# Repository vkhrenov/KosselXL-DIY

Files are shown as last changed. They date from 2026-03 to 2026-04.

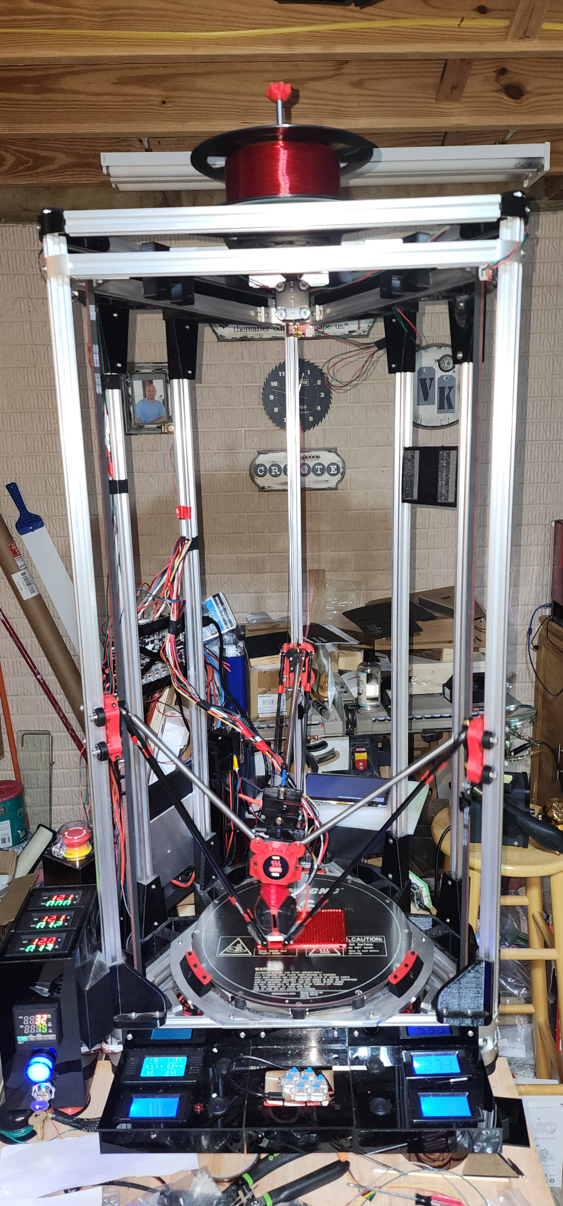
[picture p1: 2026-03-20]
Work in progress.jpg

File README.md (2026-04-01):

# KosselXL-DIY

DIY Delta 3D printer build based on a Kossel XL frame, upgraded with a BigTreeTech Manta M8P controller and Klipper firmware.

This repository documents the machine configuration, parts, and setup process.

## Project Goals

- Rebuild and modernize a classic Kossel XL style Delta printer.
- Use a modern 32-bit control board (BigTreeTech Manta M8P).
- Run Klipper for better kinematics handling and easier tuning.
- Keep the project open and easy to reproduce.

## Hardware Overview

- Frame type: Delta (Kossel XL style)
- Mainboard: BigTreeTech Manta M8P
- Firmware stack: Klipper + Moonraker + Mainsail
- Configuration files: located in `Klipper/`

Current Klipper configs in this repository:

- `Klipper/printer.cfg`
- `Klipper/mainsail.cfg`
- `Klipper/moonraker.conf`
- `Klipper/user_macros.cfg`
- `Klipper/sonar.conf`
- `Klipper/timelapse.cfg`

## Repository Structure

- `Klipper/`: machine and service configuration for Klipper stack
- `Blender/`: 3D model related files and notes
- `Parts/`: printable or mechanical part references

## Recommended Build and Setup Flow

1. Assemble frame, towers, linear motion system, and effector.
2. Install the Manta M8P and wire all components:
   - stepper motors
   - endstops
   - hotend heater and thermistor
   - bed heater and thermistor (if heated bed is used)
   - part cooling and hotend fans
   - probe/sensor (if installed)
3. Install Klipper host software (typically on a Raspberry Pi or similar Linux SBC).
4. Flash Klipper firmware to the Manta M8P.
5. Copy and adapt config files from `Klipper/` to your active Klipper config folder.
6. Verify motion direction and endstop logic before any homing test.
7. Run Delta calibration and then print tuning.

## Safety Checklist (Before First Heat or Motion)

- Confirm correct PSU voltage and grounding.
- Check all heater and thermistor ports carefully.
- Validate max temperature limits in config.
- Test endstops with `QUERY_ENDSTOPS` before homing.
- Keep one hand near power-off during first movement tests.
- Never leave first thermal tests unattended.

## Delta Calibration Checklist

After basic axis movement is verified:

1. Home the printer safely.
2. Set rough geometry values (arm length, radius, endstop positions).
3. Run Klipper Delta calibration routine.
4. Re-check first layer consistency across the full bed area.
5. Tune extrusion and temperature for your filament.

## Software and Service Notes

This project uses:

- Klipper for motion control
- Moonraker for API/service layer
- Mainsail as web UI

Service-specific configuration lives in the `Klipper/` folder and can be adapted to your environment.

## Status

Work in progress.

Planned additions:

- Wiring diagram for Manta M8P pin mapping
- BOM with exact part numbers
- Step-by-step commissioning logs
- Known-good slicer profiles

## License

See `LICENSE` for license details.

## Credits

40mm Fan Guard by Prot0typ1cal https://www.thingiverse.com/thing:1662879

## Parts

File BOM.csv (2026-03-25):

Item ID | Category | Part | Specification | Qty | Unit | Supplier | Part Number | Unit Cost | Total Cost | Status | Notes
1 | Frame | Aluminum extrusion | 2020 profile (cut to frame lengths) | 12 | pcs | TBD | TBD | 0 | 0 | To Buy | Confirm exact lengths and count
2 | Frame | Corner brackets | 2020-compatible L bracket | 24 | pcs | TBD | TBD | 0 | 0 | To Buy
3 | Motion | Linear rails or wheel system | Tower motion hardware set | 3 | sets | TBD | TBD | 0 | 0 | To Buy | Choose final tower motion design
4 | Motion | GT2 belt | 6 mm width | 5 | m | TBD | TBD | 0 | 0 | To Buy
5 | Motion | GT2 pulley | 20T 5 mm bore | 3 | pcs | TBD | TBD | 0 | 0 | To Buy
6 | Motion | GT2 idler | Smooth idler pulley | 6 | pcs | TBD | TBD | 0 | 0 | To Buy
7 | Motion | Stepper motor | NEMA 17 (X/Y/Z towers) | 3 | pcs | TBD | TBD | 0 | 0 | To Buy
8 | Motion | Extruder stepper | NEMA 17 (extruder) | 1 | pcs | TBD | TBD | 0 | 0 | To Buy
9 | Extrusion | Extruder | Titan or equivalent | 1 | pcs | TBD | TBD | 0 | 0 | To Buy
10 | Extrusion | Hotend | E3D V6 compatible | 1 | pcs | TBD | TBD | 0 | 0 | To Buy
11 | Thermal | Heater cartridge | 24 V 40 W | 1 | pcs | TBD | TBD | 0 | 0 | To Buy
12 | Thermal | Thermistor | NTC 100K | 1 | pcs | TBD | TBD | 0 | 0 | To Buy
13 | Cooling | Part cooling fan | 5015 blower 24 V | 1 | pcs | TBD | TBD | 0 | 0 | To Buy
14 | Cooling | Hotend fan | 4010 fan 24 V | 1 | pcs | TBD | TBD | 0 | 0 | To Buy
15 | Electronics | Mainboard | BigTreeTech Manta M8P | 1 | pcs | TBD | TBD | 0 | 0 | To Buy
16 | Electronics | Stepper drivers | TMC2209 or equivalent | 4 | pcs | TBD | TBD | 0 | 0 | To Buy | Update qty if adding more motors
17 | Electronics | SBC | Raspberry Pi or equivalent | 1 | pcs | TBD | TBD | 0 | 0 | To Buy
18 | Electronics | Power supply | 24 V PSU (sized for heaters + motors) | 1 | pcs | TBD | TBD | 0 | 0 | To Buy
19 | Electronics | Endstops | Mechanical or optical endstop switches | 3 | pcs | TBD | TBD | 0 | 0 | To Buy
20 | Bed | Build plate | Glass/PEI build surface | 1 | pcs | TBD | TBD | 0 | 0 | To Buy
21 | Bed | Heated bed | Round bed 24 V (optional) | 1 | pcs | TBD | TBD | 0 | 0 | Optional
22 | Wiring | Wire set | Silicone wire assorted gauges | 1 | set | TBD | TBD | 0 | 0 | To Buy
23 | Wiring | Connectors | Ferrules/JST/XH set | 1 | set | TBD | TBD | 0 | 0 | To Buy
24 | Fasteners | Screw assortment | M3/M4 screws nuts washers spacers | 1 | set | TBD | TBD | 0 | 0 | To Buy
25 | Printed Parts | Printable parts bundle | All STL files in Parts folder | 1 | bundle | Self print | N/A | 0 | 0 | In Progress | Track filament usage separately
26 | Tools | Crimping and assembly tools | Crimper hex keys cutters multimeter | 1 | set | Existing | N/A | 0 | 0 | Have | Only buy missing tools
27 | Spares | Consumables | Nozzles PTFE ties heatshrink | 1 | set | TBD | TBD | 0 | 0 | To Buy
28 | Documentation | Wiring labels | Heat-resistant cable labels | 1 | set | TBD | TBD | 0 | 0 | To Buy
 |  | TOTAL |  |  |  |  |  |  | 0

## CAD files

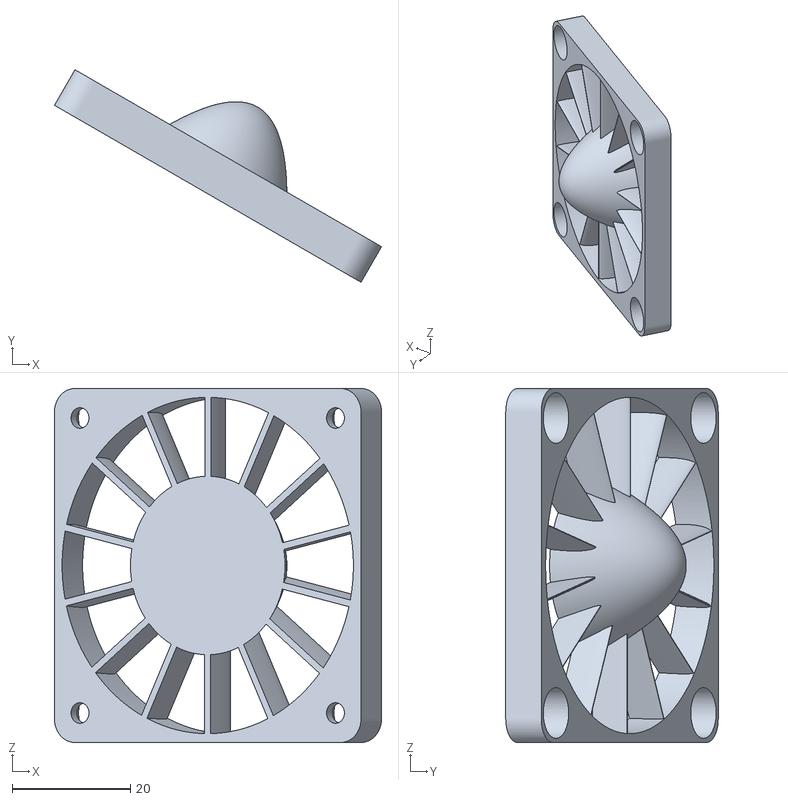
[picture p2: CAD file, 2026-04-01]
Parts/KosselXL-DIY-Fan_guard_60_back.stl
55.4 x 36.0 x 60.0

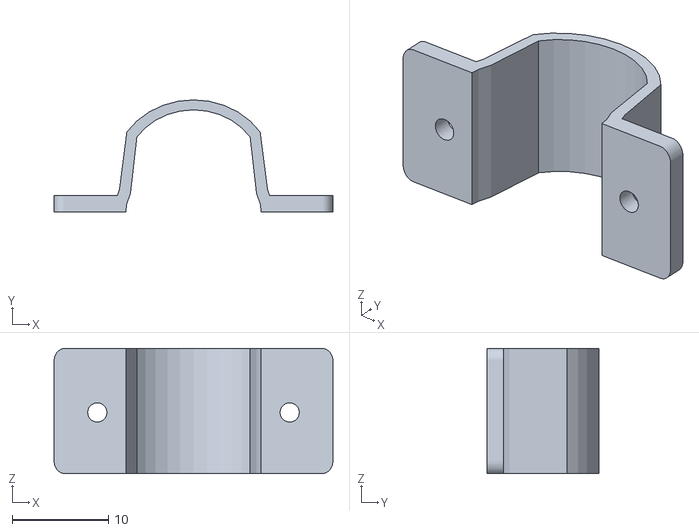
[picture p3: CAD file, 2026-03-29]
Parts/KosselXL-DIY-Wire_holder.stl
29.0 x 11.7 x 13.0

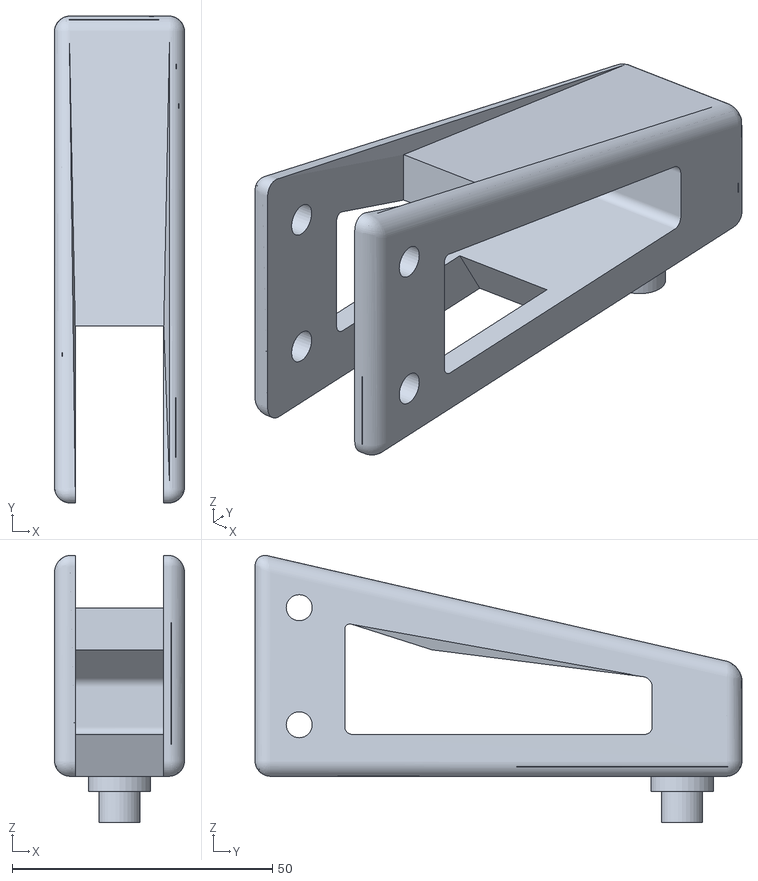
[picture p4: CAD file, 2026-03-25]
Parts/KosselXL-DIY-Guide.stl
25.0 x 93.6 x 51.3

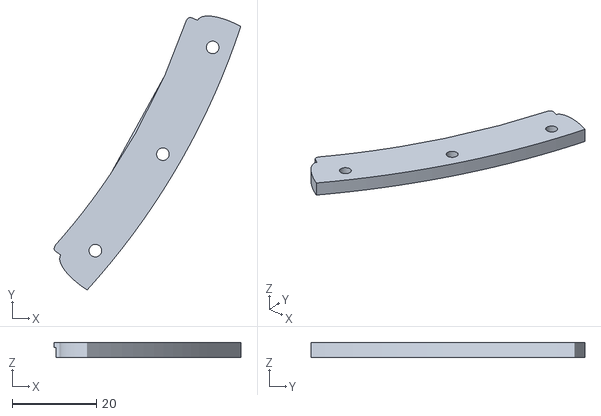
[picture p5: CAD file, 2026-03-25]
Parts/KosselXL-DIY-Build plate holder glass_Y.stl
44.3 x 65.1 x 3.50

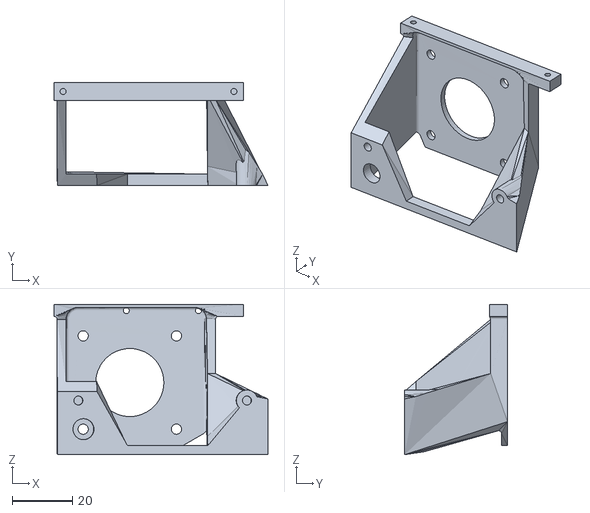
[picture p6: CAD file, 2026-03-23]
Parts/KosselXL-DIY-Titan_Mount.stl
71.1 x 34.2 x 50.0

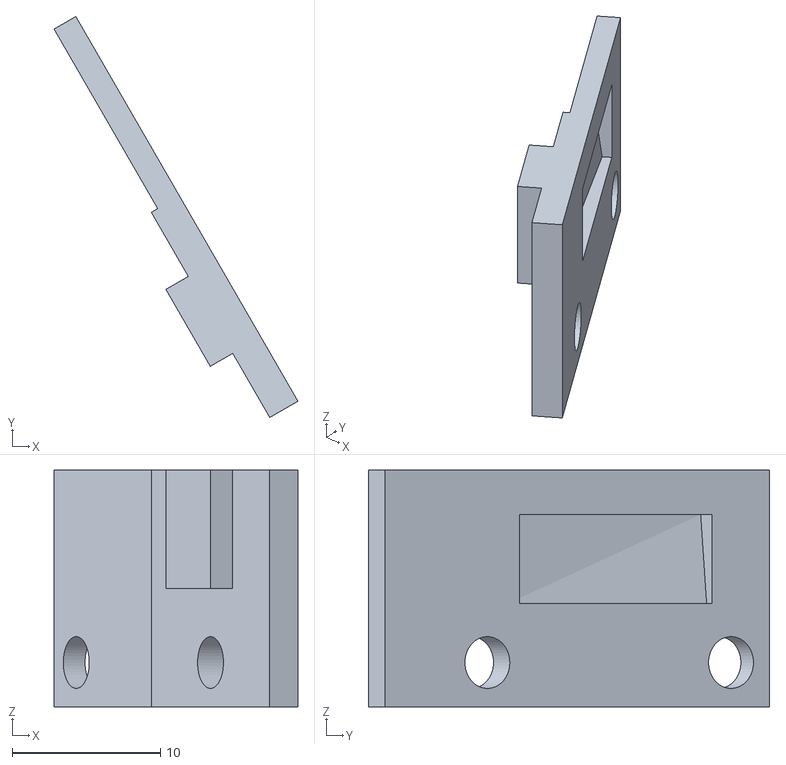
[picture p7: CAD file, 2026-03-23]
Parts/KosselXL-DIY-end_stop_mount_X.stl
16.5 x 27.1 x 16.0

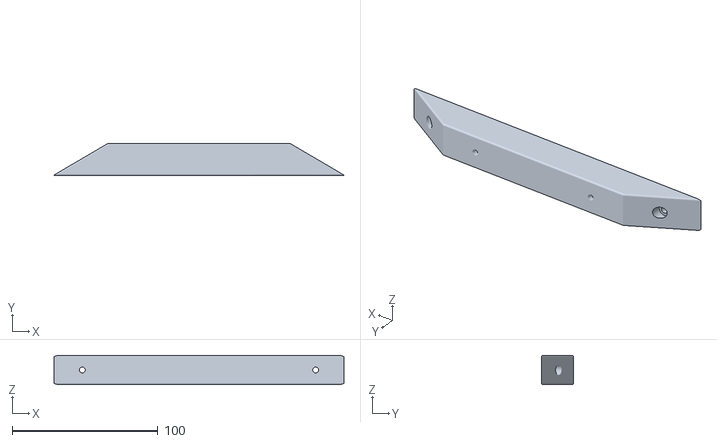
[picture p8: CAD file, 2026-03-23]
Parts/KosselXL-DIY-Spool mount holder.stl
198.9 x 22.0 x 20.0

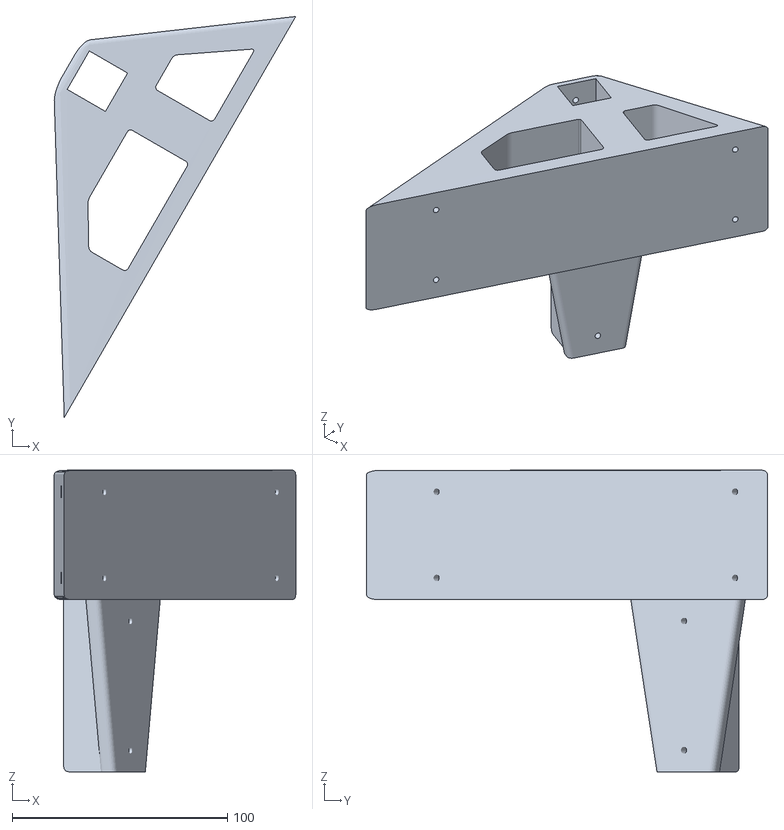
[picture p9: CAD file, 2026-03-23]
Parts/KosselXL-DIY-Reinforcement frame mount LT2.stl
112.1 x 186.2 x 140.0

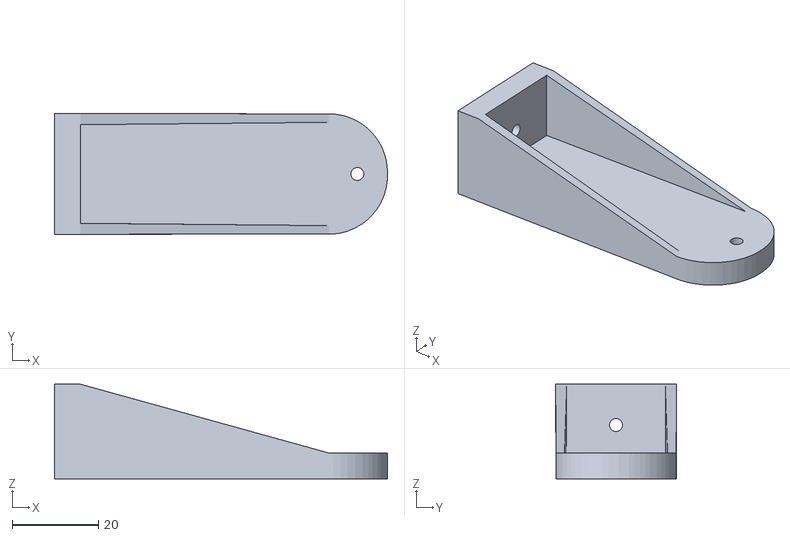
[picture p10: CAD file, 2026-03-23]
Parts/KosselXL-DIY-Upper Light right holder.stl
77.4 x 28.0 x 22.0

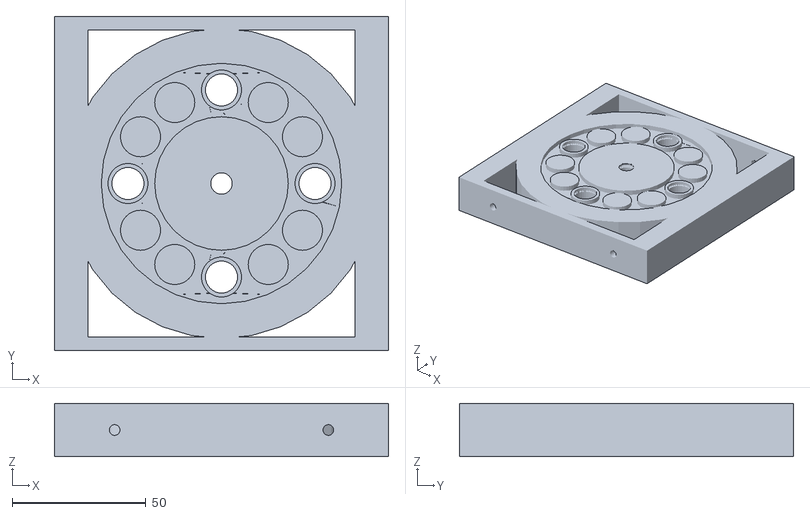
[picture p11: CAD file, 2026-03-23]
Parts/KosselXL-DIY-Spool Mount.stl
125.0 x 125.0 x 20.0

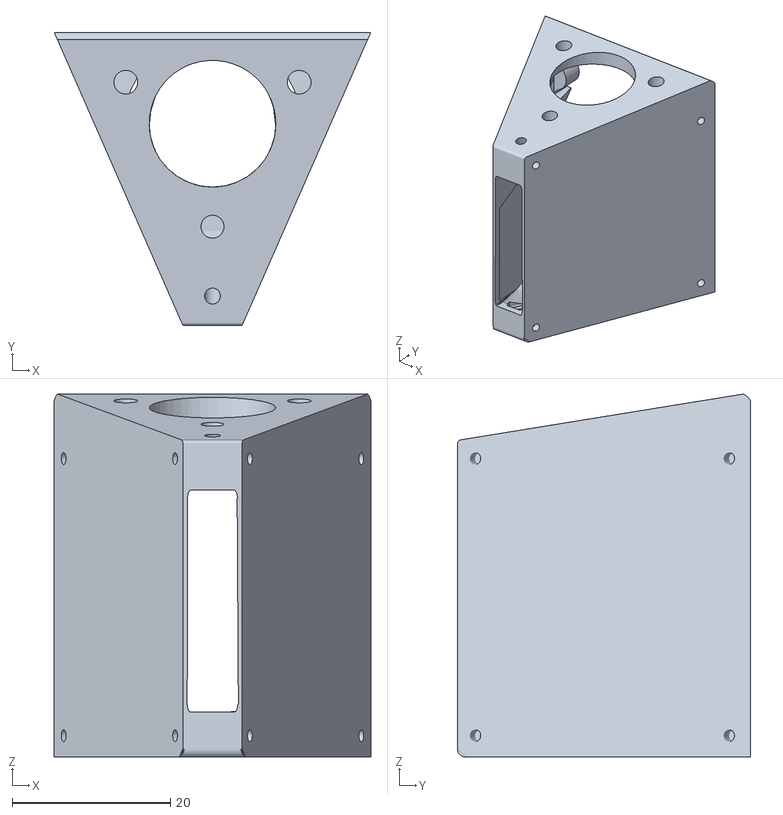
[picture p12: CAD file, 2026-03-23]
Parts/KosselXL-DIY-Frame.stl
40.0 x 37.1 x 45.9

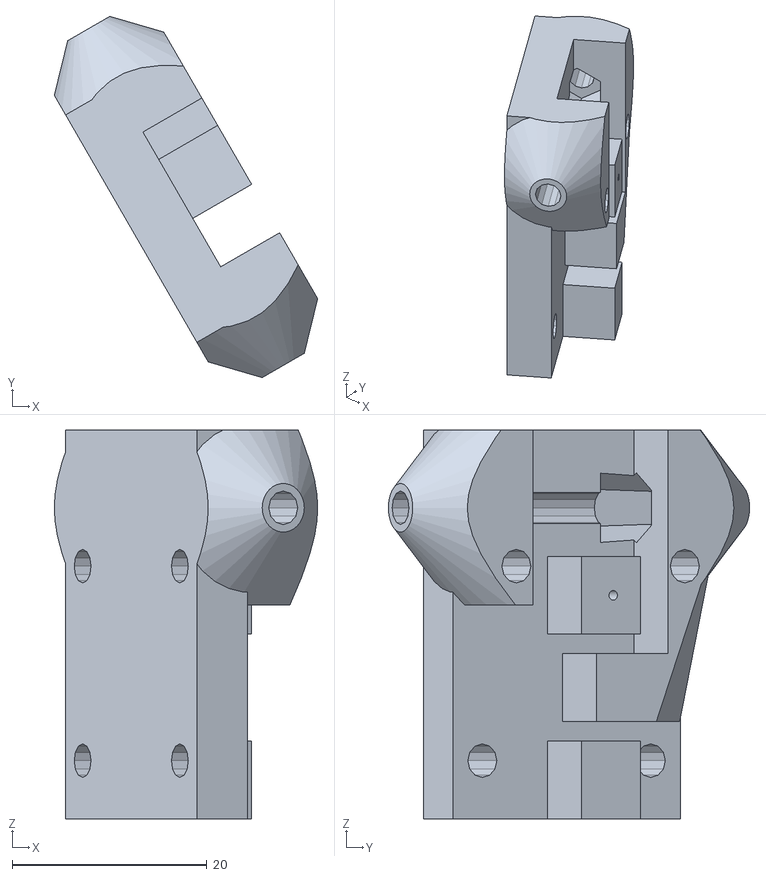
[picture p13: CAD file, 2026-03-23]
Parts/KosselXL-DIY-3X carriage_X.stl
27.1 x 37.1 x 40.0

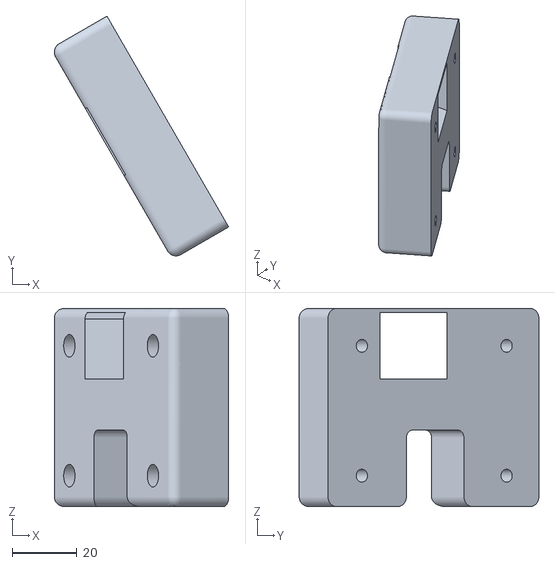
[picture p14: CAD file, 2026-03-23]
Parts/KosselXL-DIY-Right Center beam mount.stl
53.7 x 73.8 x 61.0

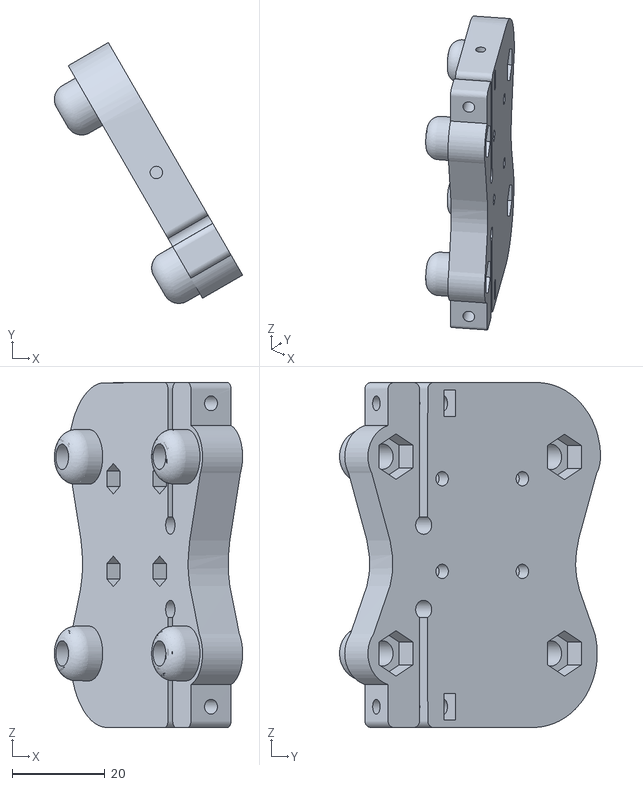
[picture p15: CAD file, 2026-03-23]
Parts/KosselXL-DIY-4Wheel_carraige_X.stl
40.6 x 56.3 x 74.5

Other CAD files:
Parts/KosselXL-DIY-Fan_guard_60_front.stl
Parts/KosselXL-DIY-Neck.stl
Parts/KosselXL-DIY-Spring_mount_front.stl
Parts/KosselXL-DIY-e3d_holder.stl
Parts/KosselXL-DIY-4Wheel_carraige_v1.stl
Parts/KosselXL-DIY-Build Plate Holder_Y.stl
Parts/KosselXL-DIY-EndStop callibrator.stl
Parts/KosselXL-DIY-Fan_shroud_right.stl
Parts/KosselXL-DIY-Guide base.stl
Parts/KosselXL-DIY-Guide wheel spacer.stl
Parts/KosselXL-DIY-Left Center beam mount.stl
Parts/KosselXL-DIY-Left beam mount.stl
Parts/KosselXL-DIY-Light_Insert.stl
Parts/KosselXL-DIY-Light_top.stl
Parts/KosselXL-DIY-Right beam mount.stl
Parts/KosselXL-DIY-Spring_mount_back.stl
Parts/KosselXL-DIY-TAPA_PERFIL_20x20_T5.7.stl
Parts/KosselXL-DIY-Thermister_cover.stl
Parts/KosselXL-DIY-Upper Light left holder.stl

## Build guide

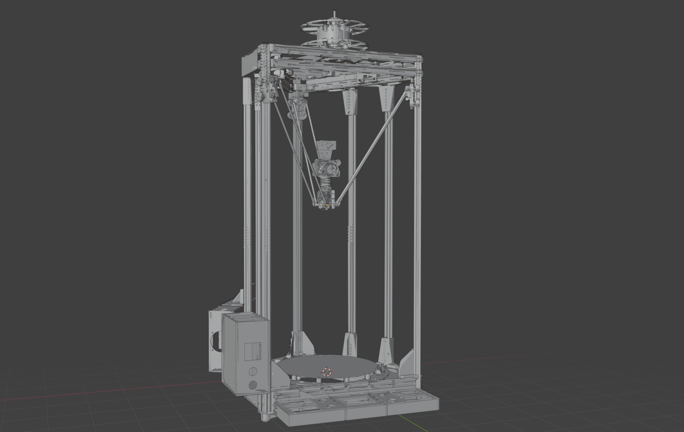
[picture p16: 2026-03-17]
3D Printer.jpg

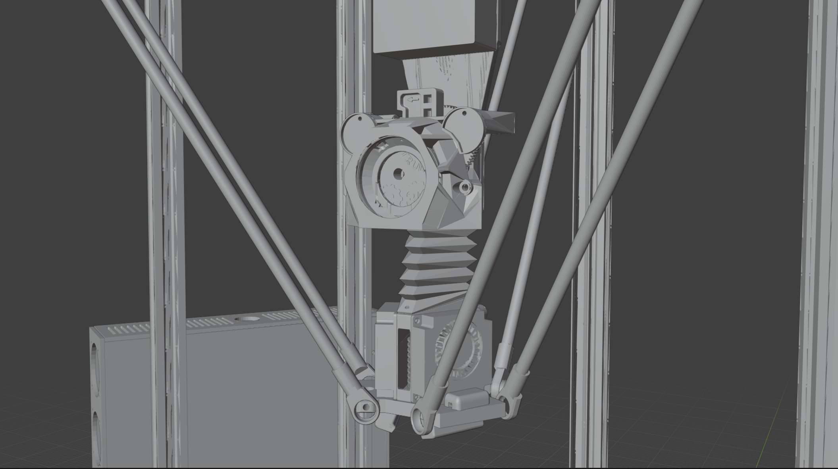
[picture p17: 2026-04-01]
HotEnd Assembly.jpg

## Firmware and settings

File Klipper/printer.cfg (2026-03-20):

# This file contains common pin mappings for the BIGTREETECH Manta M8P V2.0
# To use this config, the firmware should be compiled for the
# STM32H723 with a "128KiB bootloader" "25 MHz crystal"
# and "USB (on PA11/PA12)", "CAN bus (on PD0/PD1)" or Serial (on USART1 PA10/PA9).

# See docs/Config_Reference.md for a description of parameters.
[include mainsail.cfg]
[include user_macros.cfg]

[idle_timeout]
timeout: 1800  ; Sets timeout to 1 hour (in seconds)
gcode:
    TURN_OFF_HEATERS
    M84 ; Disable motors

# Motor1
[stepper_a]
step_pin: PE6
dir_pin: PE5
enable_pin: !PC14
microsteps: 16
rotation_distance: 40
endstop_pin: ^!PF4
homing_speed: 60
# The next parameter needs to be adjusted for
# your printer. You may want to start with 280
# and meassure the distance from nozzle to bed.
# This value then needs to be added.
#position_endstop:464.38
#arm_length: 405.600000     # Note! The actual diagonal_rod is 400mm but the effective arm length is longer due to the diagonal ball joints. This value is a good starting point but may need to be adjusted for your printer.

# Motor2
[stepper_b]
step_pin: PE2
dir_pin: PE1
enable_pin: !PE4
microsteps: 16
rotation_distance: 40
endstop_pin: ^!PF3
homing_speed: 60

# Motor3
[stepper_c]
step_pin: PB8
dir_pin: PB7
enable_pin: !PE0
microsteps: 16
rotation_distance: 40
endstop_pin: ^!PF2
homing_speed: 60

## Motor4
# The M8P only has 4 heater outputs which leaves an extra stepper
# This can be used for a second Z stepper, dual_carriage, extruder co-stepper,
# or other accesory such as an MMU
#[stepper_]
#step_pin: PB4
#dir_pin: PB3
#enable_pin: !PB6
#endstop_pin: ^PF1
#...

# Motor5
[extruder]
step_pin: PG13
dir_pin: PG12
enable_pin: !PG15
microsteps:  16
# Titan extruder
rotation_distance: 7.5

nozzle_diameter: 0.4
filament_diameter: 1.75
heater_pin: PA0 # HE0
sensor_pin: PB0 # T0
sensor_type: EPCOS 100K B57560G104F
max_extrude_only_velocity: 25
max_extrude_only_accel: 400
#max_extrude_only_velocity: 30
#max_extrude_only_accel: 500
#max_extrude_only_distance: 6
#control = pid
#pid_kp = 46.214
#pid_ki = 4.969
#pid_kd = 107.447

min_extrude_temp: 150
min_temp: 0
max_temp: 320

## End-Stop 5
#[filament_switch_sensor material_0]
#switch_pin: PF0

## Motor6
#[extruder1]
#step_pin: PG9
#dir_pin: PD7
#enable_pin: !PG11 
#heater_pin: PA1 # HE1 
#sensor_pin: PC5 # T1
#...

## End-Stop 6
#[filament_switch_sensor material_1]
#switch_pin: PC15

## Motor7
#[extruder2]
#step_pin: PD4
#dir_pin: PD3
#enable_pin: !PD6
#heater_pin: PA3 # HE2
#sensor_pin: PC4 # T2
#...

## Motor8
#[extruder3]
#step_pin: PC7
#dir_pin: PC8
#enable_pin: !PD2
#heater_pin: PA5 # HE3
#sensor_pin: PA7 # T3
#...

[heater_bed]
heater_pin: PF5
sensor_pin: PB1 # TB 
sensor_type: EPCOS 100K B57560G104F
control: watermark
min_temp: 0
max_temp: 130
max_power: 1.0

[verify_heater heater_bed]
check_gain_time: 360 # (default is usually 60)
hysteresis: 15
max_error: 1200

#[fan_generic soc-fan]
#pin: host:gpio79  #CB1
#pin: host:gpio26  #CM4

# Fan0
[fan]
pin: PF7
max_power: 1.0
kick_start_time: 0.5
off_below: 0.1

## Fan1
[heater_fan hotend_fan]
pin: PF9
heater: extruder
heater_temp: 50.0

## Fan2
#[heater_fan fan2]
#pin: PF6

## Fan3
#[heater_fan fan3]
#pin: PF8

## Fan4
#[heater_fan fan4]
#pin: PA4

## Fan5
#[heater_fan fan5]
#pin: PA6
#tachometer_pin: PC2

## Fan6
[temperature_fan pi_fan]
pin: !PA2
max_power: 1.0
sensor_type: temperature_host
control: watermark
target_temp: 48 # Target temperature to maintain (Celsius)
min_temp: 0
max_temp: 90
off_below: 0.10
kick_start_time: 0.50
max_speed: 0.8 # Adjust max speed if a specific fan speed limit is desired
min_speed: 0.3 # Adjust min speed for minimum operation

#tachometer_pin: PC1

[temperature_sensor extruder_motor]
sensor_type: EPCOS 100K B57560G104F
sensor_pin: PC5
min_temp: 0
max_temp: 75

[mcu]
serial: /dev/serial/by-id/usb-Klipper_stm32h723xx_47002D001251313531383332-if00

[printer]
kinematics: delta
max_velocity: 80  #400
max_accel: 2000 #3000
max_z_velocity: 80 # 200
max_z_accel: 100

delta_radius = 217.5 # (DELTA_SMOOTH_ROD_OFFSET-DELTA_EFFECTOR_OFFSET-DELTA_CARRIAGE_OFFSET)  F.ex. 272 - 30 - 28
# KosselXL DIY: 215.95
# DELTA_SMOOTH_ROD_OFFSET = 268.5
# DELTA_EFFECTOR_OFFSET = 22.22
# DELTA_CARRIAGE_OFFSET = 28
# DELTA_EFFECTOR_OFFSET = distance between the effectoe center to the diagonal ball / sqrt(3) or 1.732 
# if you want to DELTA_CALIBRATE you may need that
minimum_z_position: -5

[delta_calibrate]
radius: 120

[bed_mesh]
speed: 60
horizontal_move_z: 8
mesh_radius: 120
mesh_origin: 0, 0
round_probe_count: 7
algorithm: bicubic

# Runout switch
[filament_switch_sensor filament_sensor]
switch_pin: PF0
pause_on_runout: False
runout_gcode:
    FILAMENT_RUNOUT
insert_gcode:
    FILAMENT_INSERT
event_delay: 1.0

# Motion / jam detection
[filament_motion_sensor filament_motion]
switch_pin: PC15
extruder: extruder
detection_length: 10
pause_on_runout: False
runout_gcode:
    FILAMENT_RUNOUT


########################################
# TMC2209 configuration
########################################

# Motor1
[tmc2209 stepper_a]
uart_pin: PC13
#diag_pin: PF4 
run_current: 0.800
stealthchop_threshold: 999999

# Motor2
[tmc2209 stepper_b]
uart_pin: PE3
#diag_pin: PF3
run_current: 0.800
stealthchop_threshold: 999999

# Motor3
[tmc2209 stepper_c]
uart_pin: PB9
#diag_pin: PF2
run_current: 0.8
stealthchop_threshold: 999999

## Motor4
#[tmc2209 stepper_]
#uart_pin: PB5
##diag_pin: PF1
#run_current: 0.650
#stealthchop_threshold: 999999

# Motor5
[tmc2209 extruder]
uart_pin: PG14
#run_current: 0.800
run_current: 0.55
hold_current: 0.3
stealthchop_threshold: 999999

## Motor6
#[tmc2209 extruder1]
#uart_pin: PG10
#run_current: 0.800
#stealthchop_threshold: 999999

## Motor7
#[tmc2209 extruder2]
#uart_pin: PD5
#run_current: 0.800
#stealthchop_threshold: 999999

## Motor8
#[tmc2209 extruder3]
#uart_pin: PC6
#run_current: 0.800
#stealthchop_threshold: 999999

########################################
# TMC2130 configuration
########################################

## Motor1
#[tmc2130 stepper_x]
#cs_pin: PC13
#spi_software_mosi_pin: PG6
#spi_software_miso_pin: PG7
#spi_software_sclk_pin: PG8
##diag1_pin: PF4
#run_current: 0.800
#stealthchop_threshold: 999999

## Motor2
#[tmc2130 stepper_y]
#cs_pin: PE3
#spi_software_mosi_pin: PG6
#spi_software_miso_pin: PG7
#spi_software_sclk_pin: PG8
##diag1_pin: PF3
#run_current: 0.800
#stealthchop_threshold: 999999

## Motor3
#[tmc2130 stepper_z]
#cs_pin: PB9
#spi_software_mosi_pin: PG6
#spi_software_miso_pin: PG7
#spi_software_sclk_pin: PG8
##diag1_pin: PF2
#run_current: 0.650
#stealthchop_threshold: 999999

## Motor4
#[tmc2130 stepper_]
#cs_pin: PB5
#spi_software_mosi_pin: PG6
#spi_software_miso_pin: PG7
#spi_software_sclk_pin: PG8
##diag1_pin: PF1
#run_current: 0.800
#stealthchop_threshold: 999999

## Motor5
#[tmc2130 extruder]
#cs_pin: PG14
#spi_software_mosi_pin: PG6
#spi_software_miso_pin: PG7
#spi_software_sclk_pin: PG8
#run_current: 0.800
#stealthchop_threshold: 999999

## Motor6
#[tmc2130 extruder1]
#cs_pin: PG10
#spi_software_mosi_pin: PG6
#spi_software_miso_pin: PG7
#spi_software_sclk_pin: PG8
#run_current: 0.800
#stealthchop_threshold: 999999

## Motor7
#[tmc2130 extruder2]
#cs_pin: PD5
#spi_software_mosi_pin: PG6
#spi_software_miso_pin: PG7
#spi_software_sclk_pin: PG8
#run_current: 0.800
#stealthchop_threshold: 999999

## Motor8
#[tmc2130 extruder3]
#cs_pin: PC6
#spi_software_mosi_pin: PG6
#spi_software_miso_pin: PG7
#spi_software_sclk_pin: PG8
#run_current: 0.800
#stealthchop_threshold: 999999

[board_pins]
aliases:
    # EXP1 header
    EXP1_1=PE7, EXP1_2=PG1,
    EXP1_3=PG0, EXP1_4=PF15,
    EXP1_5=PF14, EXP1_6=PF13,    # Slot in the socket on this side
    EXP1_7=PF12, EXP1_8=PF11,
    EXP1_9=<GND>, EXP1_10=<5V>,

    # EXP2 header
    EXP2_1=PE13, EXP2_2=PE12,
    EXP2_3=PE15, EXP2_4=PE11,
    EXP2_5=PE10, EXP2_6=PE14,      # Slot in the socket on this side
    EXP2_7=PE8, EXP2_8=<RST>,
    EXP2_9=<GND>, EXP2_10=<NC>

[exclude_object]

# See the sample-lcd.cfg file for definitions of common LCD displays.

#[adxl345]
#cs_pin: PA15
#spi_bus: spi3a

[bltouch]
sensor_pin: ^PD13
control_pin: PD12

x_offset: 0
y_offset: 31.3
#z_offset: 0         

pin_move_time: 0.7
stow_on_each_sample: True
samples: 2

probe_with_touch_mode: True
pin_up_touch_mode_reports_triggered: False
pin_up_reports_not_triggered: True

  
## Proximity switch
#[probe]
#pin: PD8

#[output_pin ps_on_pin]
#pin: PD14

#[neopixel my_neopixel_1]
#pin: PD15

#[hall_filament_width_sensor]
#adc1: PC0
#adc2: PF10
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

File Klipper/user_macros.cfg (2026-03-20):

# PROBE CALIBRATION
[gcode_macro PROBE_CALIBRATION]
description: Safe PROBE_CALIBRATE for delta
gcode:
    G28
    G90
    G1 X0 Y0 Z20 F6000
    PROBE_CALIBRATE

# PARK AFTER PAUSE
[gcode_macro _TOOLHEAD_PARK_PAUSE_CANCEL]
description: Delta-safe smart park (center only)
gcode:
  {% set client = printer['gcode_macro _CLIENT_VARIABLE']|default({}) %}
  {% set velocity = printer.configfile.settings.pause_resume.recover_velocity %}
  {% set park_dz = client.custom_park_dz|default(8.0)|abs %}
  {% set sp_hop  = client.speed_hop|default(20) * 60 %}
  {% set sp_move = client.speed_move|default(velocity) * 60 %}

  {% set act = printer.gcode_move.gcode_position %}
  {% set max = printer.toolhead.axis_maximum %}
  {% set origin = printer.gcode_move.homing_origin %}

  {% set safety = 2.0 %}
  {% set z_max_safe = max.z - origin.z - safety %}
  {% set lift = park_dz if act.z + park_dz <= z_max_safe else z_max_safe - act.z %}
  {% if lift < 0 %}{% set lift = 0 %}{% endif %}

  _CLIENT_RETRACT

  {% if "xyz" in printer.toolhead.homed_axes %}
    G91
    {% if lift > 0 %}
      G1 Z{lift|round(3)} F{sp_hop}
    {% endif %}
    G90
    G1 X0 Y0 F{sp_move}
  {% else %}
    RESPOND TYPE=echo MSG="Printer not homed"
  {% endif %}


# FILAMENT RUNOUT
[gcode_macro FILAMENT_RUNOUT]
description: Smart filament runout handling
gcode:
    M400
    PAUSE
    RESPOND MSG="Filament runout detected"
    
    # Lift head safely
    {% set z = printer.toolhead.position.z + 10 %}
    {% if z > printer.toolhead.axis_maximum.z %}
        {% set z = printer.toolhead.axis_maximum.z %}
    {% endif %}
    
    G91
    G1 Z10 F1200
    G90
    
    # Move to safe center (best for delta)
    G1 X0 Y0 F6000
    
    # Retract filament from hotend
    G91
    G1 E-30 F1200
    G90

# FILAMENT INSERT    
[gcode_macro FILAMENT_INSERT]
description: Resume after filament insert
gcode:
    RESPOND MSG="Filament inserted"

# LOAD FILAMENT
[gcode_macro LOAD_FILAMENT]
gcode:
    M109 S{printer.extruder.target}
    G91
    G1 E40 F300
    G1 E20 F120
    G90

# RESUME PRINT
[gcode_macro RESUME_PRINT]
gcode:
    G91
    G1 E10 F200
    G90
    RESUME

# PRINT_END
[gcode_macro PRINT_END]
gcode:
    M400
    G92 E0
    G1 E-2 F3600
    TURN_OFF_HEATERS
    G91
    G1 Z10 F3000
    G90
    G1 X0 Y0 F6000
    M84
    
    

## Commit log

2026-03-17 STL Parts added
    [KosselXL-DIY-4Wheel_carraige_v1.stl, KosselXL-DIY-EndStop callibrator.stl, KosselXL-DIY-Fan_shroud_right.stl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]
2026-03-20 My current klipper configs are added
    [mainsail.cfg, printer.cfg, timelapse.cfg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]
2026-03-23 Light insert and wire holder size adjusted
    [KosselXL-DIY-3X carriage_X.stl, KosselXL-DIY-4Wheel_carraige_X.stl, KosselXL-DIY-Build Plate Holder_Y.stl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]
2026-03-25 initial BOM createdf
    [BOM.csv, KosselXL-DIY-Build plate holder glass_Y.stl, KosselXL-DIY-Guide.stl]
2026-03-29 Wireholder size increased
    [KosselXL-DIY-Wire_holder.stl]
2026-03-31 Manta M8P V2 enclosure added
2026-04-01 BTT enclosure
2026-04-01 Fan guards added
    [KosselXL-DIY-Fan_guard_60_back.stl, KosselXL-DIY-Fan_guard_60_front.stl]
2026-04-13 Manta mounting box holes adjusted, Antenna hole added
